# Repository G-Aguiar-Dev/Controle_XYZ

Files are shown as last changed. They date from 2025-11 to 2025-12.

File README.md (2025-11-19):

# 🏭 Controle XYZ - Sistema Automatizado de Armazém

**Sistema inteligente de armazenagem com CNC 3018, RFID e interface web**

[Início Rápido](#-início-rápido) • [Recursos](#-recursos) • [Hardware](#-hardware) • [Instalação](#-instalação) • [Documentação Completa](./DOCUMENTATION.md)

</div>

---

## 🎯 O que é?

**Controle XYZ** é um sistema automatizado de armazenagem executado em uma **Raspberry Pi Pico W**. Ele utiliza uma máquina CNC 3018 para movimentar pallets entre 6 posições de armazenamento, identificação por RFID, eletroímã para manipulação e uma interface web intuitiva para controle remoto.

O sistema funciona com **FreeRTOS** para multitarefa em tempo real e oferece um backend Flask com banco de dados SQLite para gestão de inventário e logs.

---

## ✨ Recursos Principais

- ✅ **Automação CNC 3D**: Movimento preciso em 3 eixos (X, Y, Z) com 6 posições de armazenamento
- ✅ **Identificação RFID**: Leitura automática de UIDs dos pallets (MFRC522)
- ✅ **Eletroímã Inteligente**: Pegar e soltar pallets automaticamente
- ✅ **Interface Web Responsiva**: Painel de controle moderno com real-time updates
- ✅ **Multitarefa em Tempo Real**: FreeRTOS com 2 tasks prioritárias
- ✅ **Display LCD**: Feedback visual no display 16x2 com I2C
- ✅ **Wi-Fi Integrado**: Servidor HTTP nativo no Pico W
- ✅ **Backend Python**: Gerenciamento de banco de dados SQLite
- ✅ **Sistema de Log Circular**: Histórico de operações em memória
- ✅ **Thread-Safe**: Proteção com mutexes para operações críticas

---

## 🔧 Hardware Necessário

| Componente | Especificação | Função |
|---|---|---|
| **Microcontrolador** | Raspberry Pi Pico W | Cérebro do sistema |
| **Motor XY** | NEMA 17 (2 unidades) | Movimentação horizontal |
| **Motor Z** | NEMA 17 | Movimentação vertical |
| **Drivers** | A4988 (3 unidades) | Controle dos motores |
| **Sensores** | Endstops (6 unidades) | Limites de movimento |
| **RFID** | MFRC522 | Identificação de pallets |
| **Eletroímã** | 24V DC | Pegar/soltar pallets |
| **Display** | LCD 16x2 I2C | Interface visual |
| **Máquina Base** | CNC 3018 | Estrutura mecânica |
| **Wi-Fi** | Integrado (Pico W) | Conectividade |

---

## 🚀 Início Rápido

### 1️⃣ Clonar o Repositório
```bash
git clone https://github.com/G-Aguiar-Dev/Controle_XYZ.git
cd Controle_XYZ
```

### 2️⃣ Compilar o Firmware
```bash
mkdir build && cd build
cmake ..
make -j4
```

### 3️⃣ Fazer Upload para Pico W
- Pressione **BOOTSEL** enquanto conecta o cabo USB
- Copie `Controle_XYZ.uf2` para a unidade PICO montada

### 4️⃣ Iniciar Backend Flask
```bash
python dbServer.py
```

### 5️⃣ Acessar a Interface
- Descobrir IP do Pico: Verifique saída serial
- Abrir navegador: `http://<IP_PICO>`

---

## 📁 Estrutura do Projeto

```
Controle_XYZ/
├── Controle_XYZ.c          # Firmware principal
├── CMakeLists.txt          # Build configuration
├── Index.html              # Interface web
├── dbServer.py             # Backend Flask
├── INSTALL.md              # Guia de instalação
├── README.md               # Este arquivo
├── DOCUMENTATION.md        # Documentação técnica completa
└── lib/
    ├── mfrc522.*           # Driver RFID
    ├── lcd_1602_i2c.*      # Driver LCD
    ├── HTML.*              # Gerador de HTML
    ├── FreeRTOSConfig.h    # Configuração FreeRTOS
    └── sqlite/             # SQLite
```

---

## 🎮 Como Usar

### Interface Web
1. **Armazenar Pallet**
   - Clique em "Iniciar Armazenamento"
   - Clique em uma célula vazia
   - Confirme a operação

2. **Retirar Pallet**
   - Clique em uma célula ocupada (amarela)
   - Confirme a remoção

3. **Controle Manual**
   - Botão de eletroímã para operações manuais
   - Visualize histórico de movimentações

### API HTTP
```bash
# Armazenar em A1
curl -X POST http://192.168.1.XX/store?slot=A1

# Retirar de B2
curl -X POST http://192.168.1.XX/retrieve?slot=B2

# Adicionar ao log
curl "http://192.168.1.XX/api/log?msg=Teste"
```

---

## 📊 Capacidade e Especificações

| Aspecto | Valor |
|---|---|
| **Posições de Armazenamento** | 6 (3 colunas × 2 linhas) |
| **Área de Trabalho** | 300mm × 180mm |
| **Velocidade XY** | ~800 µs por passo |
| **Velocidade Z** | ~1200 µs por passo |
| **Histórico de Logs** | 120 entradas (128 chars cada) |
| **Fila de Comandos** | 5 operações máximo |
| **Altura de Pickup** | 45mm |
| **Taxa de Atualização LCD** | ~1 Hz |

---

## 🔌 Configuração de Rede

```c
// Wi-Fi
SSID:  "Armazem XYZ"
PASS:  "tic37#grupo4"

// HTTP Server
PORT:  80 (Pico)
BACKEND: 5000 (Python)
```

---

## 📚 Documentação Completa

Para documentação técnica detalhada sobre funções, variáveis globais, tasks do FreeRTOS e troubleshooting, consulte:

➡️ **[DOCUMENTATION.md](./DOCUMENTATION.md)**

Inclui:
- Referência completa de funções
- Configuração de pinos GPIO
- Constantes de sistema
- Tasks do FreeRTOS
- Backend Flask API
- Exemplos de código

---

## 🐛 Troubleshooting Rápido

| Problema | Solução |
|---|---|
| **Wi-Fi não conecta** | Verifique SSID/senha e proximidade do roteador |
| **Motores não se movem** | Verifique alimentação dos drivers A4988 |
| **LCD em branco** | Confirme endereço I2C (0x27) e conexão |
| **RFID não lê cartão** | Verifique posicionamento e pinos SPI |
| **Homing não funciona** | Teste endstops com multímetro |

Mais detalhes em [DOCUMENTATION.md → Troubleshooting](./DOCUMENTATION.md#-troubleshooting)

---

## 📋 Requisitos de Compilação

- **Pico SDK** v1.5.0+
- **CMake** 3.13+
- **ARM GCC Toolchain**
- **FreeRTOS** com suporte RP2040
- **Python 3.8+** (para backend)

Veja [INSTALL.md](./INSTALL.md) para instruções completas de setup.

---

## 🔄 Fluxo de Operação

```
┌─────────────────────────────────────────────────┐
│  Sistema Inicia                                 │
│  1. Inicializa I2C/LCD                          │
│  2. Conecta Wi-Fi                               │
│  3. Inicializa RFID                             │
│  4. Cria Tasks FreeRTOS                         │
│  5. Executa Homing completo (0,0,0)             │
└─────────────────────────────────────────────────┘
                    ↓
┌─────────────────────────────────────────────────┐
│  Aguardando Comandos                            │
│  - Interface Web monitora estado                │
│  - Motor Task aguarda na fila                   │
│  - Polling Task mantém Wi-Fi ativo              │
└─────────────────────────────────────────────────┘
                    ↓
┌─────────────────────────────────────────────────┐
│  Comando Recebido (ex: /store?slot=A1)          │
│  1. Valida slot                                 │
│  2. Enfileira comando                           │
│  3. Motor Task processa:                        │
│     - Move para altura segura Z                 │
│     - Move para célula XY                       │
│     - Ativa eletroímã                           │
│     - Retorna altura segura                     │
│  4. Log registrado                              │
│  5. LCD atualizado                              │
└─────────────────────────────────────────────────┘
```

---

## 🤝 Contribuindo

Sugestões e melhorias são bem-vindas! Para contribuir:

1. Faça um Fork do projeto
2. Crie uma branch para sua feature (`git checkout -b feature/AmazingFeature`)
3. Commit suas mudanças (`git commit -m 'Add some AmazingFeature'`)
4. Push para a branch (`git push origin feature/AmazingFeature`)
5. Abra um Pull Request

---

## 📞 Contato e Suporte

- **Repositório**: [G-Aguiar-Dev/Controle_XYZ](https://github.com/G-Aguiar-Dev/Controle_XYZ)
- **Issues**: [GitHub Issues](https://github.com/G-Aguiar-Dev/Controle_XYZ/issues)

---

## 📜 Licença

Projeto desenvolvido para **EmbarcaTech 2025** pelo **Grupo 4 - Vitória da Conquista**.

</div>

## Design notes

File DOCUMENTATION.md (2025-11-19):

# 📚 Documentação Detalhada - Controle XYZ

Documentação completa das funções, variáveis globais e arquitetura do sistema automatizado de armazém.

## 📋 Índice

1. [Arquitetura do Sistema](#arquitetura-do-sistema)
2. [Configuração de Hardware](#configuração-de-hardware)
3. [Constantes de Funcionamento](#constantes-de-funcionamento)
4. [API de Funções](#api-de-funções)
5. [Tasks do FreeRTOS](#tasks-do-freertos)
6. [Variáveis Globais](#variáveis-globais)
7. [Backend Flask](#backend-flask)
8. [Interface Web](#interface-web)
9. [Exemplos de Uso](#exemplos-de-uso)
10. [Troubleshooting](#troubleshooting)

---

## 🏗️ Arquitetura do Sistema

### Hardware
- **Microcontrolador**: Raspberry Pi Pico W (RP2040 com Wi-Fi)
- **Motor de Movimento**: CNC 3018 com 3 eixos (X, Y, Z)
- **Sensores de Fim de Curso**: Endstops para cada eixo
- **Leitor RFID**: MFRC522 via SPI
- **Manipulador**: Eletroímã para pegar/soltar pallets
- **Display**: LCD 16x2 com I2C
- **Conectividade**: Wi-Fi integrada, Servidor HTTP

### Software
- **SO**: FreeRTOS em tempo real
- **Linguagem Principal**: C (Pico SDK)
- **Servidor Backend**: Python com Flask (dbServer.py)
- **Interface Web**: HTML5 + JavaScript

### Estrutura do Armazém
```
Área de Trabalho CNC 3018:
- Dimensão Total: 300mm (X) × 180mm (Y)
- Zona Útil: 250mm (X) × 130mm (Y)
- Distribuição: 3 colunas (A, B, C) × 2 linhas (1, 2)
- Margem: 25mm em cada lado

Posições das Células:
┌─────────────────────────────────┐
│  A1       B1       C1           │
│  (37.84,  (100.51, (163.18,     │
│   18.25)   18.25)   18.25)       │
│                                 │
│  A2       B2       C2           │
│  (37.84,  (100.51, (163.18,     │
│   53.75)   53.75)   53.75)       │
└─────────────────────────────────┘
```

---

## 🔧 Configuração de Hardware

### Configuração de Rede
- **SSID**: `Armazem XYZ`
- **Senha**: `tic37#grupo4`
- **Porta HTTP (Pico)**: 80
- **Porta Backend Flask**: 5000

### Configuração de Pinos

#### Eixo X (Motor Passo-Passo)
| Função | Pino |
|---|---|
| STEP | 14 |
| DIR | 15 |
| ENA | 16 |
| Endstop MIN | 10 |
| Endstop MAX | 13 |

#### Eixo Y (Motor Passo-Passo)
| Função | Pino |
|---|---|
| STEP | 1 |
| DIR | 2 |
| ENA | 0 |
| Endstop MIN | 11 |
| Endstop MAX | 17 |

#### Eixo Z (Motor Passo-Passo)
| Função | Pino |
|---|---|
| STEP | 21 |
| DIR | 22 |
| ENA | 20 |
| Endstop MIN | 12 |
| Endstop MAX | 18 |

#### Periféricos
| Periférico | Tipo | Pino/Barramento |
|---|---|---|
| Eletroímã | GPIO | 7 |
| RFID MFRC522 | SPI | (definido em mfrc522.h) |
| LCD 16x2 | I2C | SDA: 8, SCL: 9 |

---

## ⚙️ Constantes de Funcionamento

```c
// Velocidade de Movimento
STEP_DELAY_XY_US = 800  // Microssegundos entre pulsos (X e Y)
STEP_DELAY_Z_US = 1200  // Microssegundos entre pulsos (Z)

// Resolução de Movimento
STEPS_PER_MM_X = 50.0   // 50 passos por mm
STEPS_PER_MM_Y = 70.0   // 70 passos por mm
STEPS_PER_MM_Z = 50.0   // 50 passos por mm

// Altitudes do Eixo Z
Z_SAFE_MM = 0.0         // Altura segura (sem colisão)
Z_PICKUP_MM = 45.0      // Altura de pegar/soltar pallet
Z_TRAVEL_MAX_MM = 45.0  // Curso máximo

// I2C Configuration
I2C_PORT = i2c0
I2C_SDA = 8
I2C_SCL = 9
I2C_ADDR = 0x27         // Endereço do LCD

// Log circular
LOG_CAP = 120           // Máximo de linhas
LOG_LINE_MAX = 128      // Máximo de caracteres por linha

// RFID
UID_STRLEN = 32         // Tamanho da string UID
```

---

## 🚀 API de Funções

### Funções de Inicialização

#### `init_cnc_pins()`
**Propósito**: Inicializa todos os pinos GPIO dos motores e sensores  
**Retorno**: `void`  
**Detalhes**:
- Configura pinos de STEP, DIR e ENA como saída
- Configura pinos de endstops como entrada
- Inicializa pino do eletroímã

---

#### `start_http_server()`
**Propósito**: Inicia o servidor HTTP para comunicação com interface web  
**Retorno**: `void`  
**Detalhes**:
- Vincula a callback de conexão TCP
- Aguarda requisições HTTP na porta 80
- Processa rotas de API (GET, POST)

---

### Funções de Movimento

#### `step_motor(uint step_pin, uint dir_pin, bool direction, uint delay_us)`
**Propósito**: Gera um pulso de passo único para um motor  
**Parâmetros**:
- `step_pin`: GPIO do sinal de STEP
- `dir_pin`: GPIO do sinal de DIREÇÃO
- `direction`: true = frente, false = trás
- `delay_us`: Delay em microssegundos entre pulsos

**Detalhes**:
- Define direção no pino DIR
- Envia pulso HIGH-LOW no pino STEP
- Aguarda o tempo especificado

---

#### `home_all_axes()`
**Propósito**: Posiciona a máquina no ponto zero (0,0,0)  
**Retorno**: `void`  
**Detalhes**:
- Move cada eixo em direção ao endstop MIN
- Para quando endstop é acionado
- Atualiza posição global para (0, 0, 0)
- **Ordem**: Z primeiro, depois X, depois Y

---

#### `move_axes_to_steps(long target_x, long target_y, long target_z)`
**Propósito**: Move os eixos para posições específicas (em passos)  
**Parâmetros**:
- `target_x`: Posição-alvo X em passos
- `target_y`: Posição-alvo Y em passos
- `target_z`: Posição-alvo Z em passos

**Detalhes**:
- Calcula diferença entre posição atual e-alvo
- Move eixos independentemente até atingir alvo
- Verifica endstops durante movimento
- Atualiza `g_current_steps_*` globais

---

#### `execute_cell_operation(int cell_index, bool is_pickup_operation)`
**Propósito**: Executa operação completa de pegar ou guardar pallet  
**Parâmetros**:
- `cell_index`: Índice da célula (0-5)
- `is_pickup_operation`: true = pegar, false = guardar

**Detalhes**:
- Move para altura segura Z
- Move para posição X,Y da célula
- Lowera Z até altura de pickup
- Ativa/desativa eletroímã
- Retorna para altura segura
- Log de operação

---

### Funções de Conversão de Posição

#### `indice_para_slot(int idx)`
**Propósito**: Converte índice do array para nome do slot  
**Retorno**: String (ex: "A1", "B2", "C1")  
**Mapeamento**:
```
Índice → Slot
0      → A1
1      → A2
2      → B1
3      → B2
4      → C1
5      → C2
```

---

#### `slot_para_indice(char *slot)`
**Propósito**: Converte nome do slot para índice do array  
**Parâmetros**: `slot` - String (ex: "A1")  
**Retorno**: Índice (0-5) ou -1 se inválido  
**Exemplos**:
```c
"A1" → 0
"B2" → 3
"C1" → 4
"X5" → -1 (inválido)
```

---

### Funções do Eletroímã

#### `inicializa_eletroima()`
**Propósito**: Inicializa GPIO do eletroímã  
**Retorno**: `void`

---

#### `ativar_eletroima()`
**Propósito**: Ativa o eletroímã (coloca pino em HIGH)  
**Retorno**: `void`  
**Efeito**: Define `electromagnet_active = true`

---

#### `desativar_eletroima()`
**Propósito**: Desativa o eletroímã (coloca pino em LOW)  
**Retorno**: `void`  
**Efeito**: Define `electromagnet_active = false`

---

#### `toggle_eletroima()`
**Propósito**: Alterna estado do eletroímã (ativa ↔ desativa)  
**Retorno**: `void`

---

### Funções de Log

#### `log_push(const char *fmt, ...)`
**Propósito**: Adiciona mensagem formatada ao histórico circular  
**Parâmetros**: `fmt` - String com formato printf, seguido de argumentos  
**Detalhes**:
- Armazena até 120 linhas
- Máximo 128 caracteres por linha
- Buffer circular (sobrescreve entradas antigas)
- Thread-safe (usa mutex interno)

**Exemplos**:
```c
log_push("CNC: Iniciando Homing...");
log_push("Pallet %s moved to %s", uid, slot);
log_push("Erro: Slot inválido %d", cell_index);
```

---

#### `const char* log_get(int idx)`
**Propósito**: Recupera mensagem de log por índice  
**Parâmetros**: `idx` - Índice (0 = mais antigo)  
**Retorno**: Ponteiro para string do log  
**Detalhes**:
- Índices válidos: 0 a `g_log_count - 1`
- Retorna mensagens em ordem cronológica

---

### Funções RFID

#### `scan_for_uid(char* uid_buffer, size_t buffer_len)`
**Propósito**: Escaneia um cartão RFID e obtém sua UID  
**Parâmetros**:
- `uid_buffer`: Buffer para armazenar UID em string
- `buffer_len`: Tamanho máximo do buffer

**Retorno**: `true` se cartão lido com sucesso, `false` caso contrário  
**Detalhes**:
- Formato da UID: "12 34 56 78" (hex com espaços)
- Tenta por ~100ms
- Para o cartão automaticamente após leitura
- Thread-safe (com pausas para FreeRTOS)

**Exemplo**:
```c
char uid[32];
if (scan_for_uid(uid, sizeof(uid))) {
    printf("UID lida: %s\n", uid);
}
```

---

### Funções LCD

#### `lcd_update_line(int line, const char *fmt, ...)`
**Propósito**: Atualiza uma linha do display LCD (thread-safe)  
**Parâmetros**:
- `line`: Número da linha (0 ou 1)
- `fmt`: String com formato printf

**Detalhes**:
- Usa mutex para evitar conflito de acesso
- Trunca automaticamente para 16 caracteres
- Formata argumentos como `printf`

**Exemplos**:
```c
lcd_update_line(0, "Sistema Online");
lcd_update_line(1, "IP: 192.168.1.10");
lcd_update_line(0, "Celula %s", slot);
```

---

### Funções HTTP

#### `http_recv(void *arg, struct tcp_pcb *tpcb, struct pbuf *p, err_t err)`
**Propósito**: Callback para receber requisições HTTP  
**Retorno**: `ERR_OK` ou código de erro LWIP  
**Rotas Processadas**:

| Rota | Método | Descrição |
|---|---|---|
| `/api/log` | GET | Adiciona mensagem ao log |
| `/api/history` | GET | Retorna histórico em JSON |
| `/store` | POST | Guarda pallet em célula |
| `/retrieve` | POST | Retira pallet de célula |
| `/toggle-electromagnet` | POST | Alterna eletroímã |
| `/home` | POST | Retorna ao ponto zero |
| `/api/inventory` | GET | Retorna status das células |

**Formato de Query**:
```
/store?slot=A1      → Guarda em célula A1
/retrieve?slot=B2   → Retira de célula B2
/api/log?msg=Teste  → Log "Teste"
```

---

#### `query_param(const char *req, const char *key, char *out, size_t outsz)`
**Propósito**: Extrai parâmetro de query string  
**Parâmetros**:
- `req`: String com requisição HTTP completa
- `key`: Chave do parâmetro (ex: "slot")
- `out`: Buffer de saída
- `outsz`: Tamanho máximo

**Retorno**: `true` se parâmetro encontrado, `false` caso contrário  
**Detalhes**:
- Decodifica URL-encoded values automaticamente
- Busca após "?" na requisição

**Exemplo**:
```c
char slot[10];
if (query_param(req, "slot", slot, sizeof(slot))) {
    printf("Slot solicitado: %s\n", slot);
}
```

---

#### `url_decode_inplace(char *s)`
**Propósito**: Decodifica string URL-encoded (modifica in-place)  
**Parâmetros**: `s` - String para decodificar  
**Exemplos**:
```
"A%201" → "A 1"
"Test%20123" → "Test 123"
```

---

### Funções de Controle de Endstops

#### `check_endstop(uint pin)`
**Propósito**: Verifica se endstop está acionado  
**Parâmetros**: `pin` - GPIO do endstop  
**Retorno**: `true` se acionado, `false` caso contrário

---

#### Helpers para Endstops
- `check_endstop_x_min()` / `check_endstop_x_max()`
- `check_endstop_y_min()` / `check_endstop_y_max()`
- `check_endstop_z_min()` / `check_endstop_z_max()`

---

## 📋 Tasks do FreeRTOS

### `vPollingTask`
**Prioridade**: 1 (baixa)  
**Pilha**: 512 bytes  
**Função**:
- Executa `cyw43_arch_poll()` a cada 1 segundo
- Mantém conexão Wi-Fi ativa
- Loop infinito

---

### `vMotorControlTask`
**Prioridade**: 3 (alta)  
**Pilha**: 1024 bytes  
**Função**:
- Inicializa pinos da CNC
- Executa homing completo na inicialização
- Aguarda comandos na fila `g_movement_queue`
- Executa operações de movimento

**Fluxo**:
```
1. Inicializa pinos
2. Executa home_all_axes()
3. Move para posição segura Z
4. Loop:
   - Aguarda comando da fila (bloqueante)
   - Se comando de home: move para (0,0,0)
   - Senão: executa operação de célula
```

---

## 📊 Variáveis Globais

### Posição Atual
```c
volatile long g_current_steps_x;  // Posição X em passos
volatile long g_current_steps_y;  // Posição Y em passos
volatile long g_current_steps_z;  // Posição Z em passos
```

### Mapas de Posição
```c
CellPosition g_cell_map[6];       // Coordenadas das 6 células
char g_cell_uids[6][32];          // UIDs armazenadas em cada célula
```

### Sincronização
```c
SemaphoreHandle_t g_inventory_mutex;  // Protege g_cell_uids
SemaphoreHandle_t g_lcd_mutex;        // Protege LCD
QueueHandle_t g_movement_queue;       // Fila de comandos (5 itens)
```

### Estado
```c
bool electromagnet_active;        // true = ativo
MFRC522Ptr_t g_mfrc;             // Instância RFID
```

### Log
```c
char g_log[120][128];            // Buffer circular de logs
int g_log_head;                  // Índice da próxima escrita
int g_log_count;                 // Número de logs válidos
```

---

## 🌐 Backend Flask (dbServer.py)

O servidor Python gerencia o banco de dados SQLite com inventário e logs.

### Endpoints de Produtos
| Rota | Método | Descrição |
|---|---|---|
| `/api/products` | GET | Lista todos os produtos |
| `/api/products` | POST | Cria novo produto |
| `/api/products/<id>` | PUT | Atualiza produto |
| `/api/products/<id>` | DELETE | Deleta produto |

### Endpoints de Pallets
| Rota | Método | Descrição |
|---|---|---|
| `/api/pallet/register` | POST | Associa UID a produto |
| `/api/pallet/<uid>` | GET | Consulta pallet |
| `/api/pallet/<uid>` | PUT | Atualiza quantidade |
| `/api/pallet/<uid>` | DELETE | Deleta pallet |

### Endpoints de Logs
| Rota | Método | Descrição |
|---|---|---|
| `/api/log` | POST | Adiciona log |
| `/api/logs` | GET | Lista logs |
| `/api/status` | GET | Status do servidor |
| `/api/clear` | DELETE | Limpa todos os logs |

---

## 🎨 Interface Web

A interface web (`Index.html`) fornece:
- **Visualização do Layout**: Grid com 6 células (A1-C2)
- **Operações de Armazenagem**: Botão para ativar modo "guardar"
- **Operações Manuais**: Controle do eletroímã
- **Histórico**: Visualização de movimentações
- **Filtro**: Filtrar logs por data

### Funcionalidades JavaScript
- Requisições FETCH para endpoints HTTP/API
- Atualização dinâmica do visual das células
- Log local com timestamp
- Comunicação em tempo real com servidor

---

## 🔍 Exemplos de Uso

### Guardar Pallet na Célula A1
```javascript
fetch('/store?slot=A1', { method: 'POST' })
  .then(res => res.json())
  .then(data => console.log(data));
```

### Retirar Pallet da Célula B2
```javascript
fetch('/retrieve?slot=B2', { method: 'POST' })
  .then(res => res.json())
  .then(data => console.log(data));
```

### Adicionar Mensagem ao Log
```javascript
fetch('/api/log?msg=Teste%20manual', { method: 'GET' });
```

### Ativar Eletroímã
```javascript
fetch('/toggle-electromagnet', { method: 'POST' })
  .then(res => res.json());
```

---

## 🐛 Troubleshooting

### Problema: "Falha ao conectar Wi-Fi"
- Verifique SSID e senha em `Controle_XYZ.c`
- Confirme que o roteador está ativo
- Verifique distância/interferência

### Problema: "Endstop não acionado durante homing"
- Verifique conexão dos endstops
- Teste pinos com multímetro
- Revise pinos em `Controle_XYZ.c`

### Problema: "LCD não exibe mensagens"
- Verifique endereço I2C (padrão 0x27)
- Teste com exemplo de LCD I2C
- Confirme conexão SDA/SCL

### Problema: "RFID não detecta cartão"
- Verifique pinos SPI (MOSI, MISO, CLK, CS, RST)
- Tente ler versão: `PCD_DumpVersionToSerial()`
- Confirme cartão é compatível (ISO 14443A)

---

## 📝 Notas Importantes

1. **Thread Safety**: Sempre use `xSemaphoreTake()` ao acessar `g_cell_uids`
2. **Altitude Z Segura**: Sempre retorne a `Z_SAFE_MM` entre operações
3. **Homing Obrigatório**: Sistema sempre faz homing no startup
4. **Buffer de Log**: Máximo 120 linhas; entradas antigas são sobrescritas
5. **Velocidade de Movimento**: Ajuste `STEP_DELAY_*_US` para otimizar

---

## 📞 Referências Externas

- **Pico SDK**: https://github.com/raspberrypi/pico-sdk
- **FreeRTOS**: https://www.freertos.org/
- **LWIP**: https://savannah.nongnu.org/projects/lwip/
- **MFRC522**: http://www.nxp.com/documents/data_sheet/MFRC522.pdf
- **LCD 1602 I2C**: https://lastminuteengineers.com/lcd-i2c-address-scanner/

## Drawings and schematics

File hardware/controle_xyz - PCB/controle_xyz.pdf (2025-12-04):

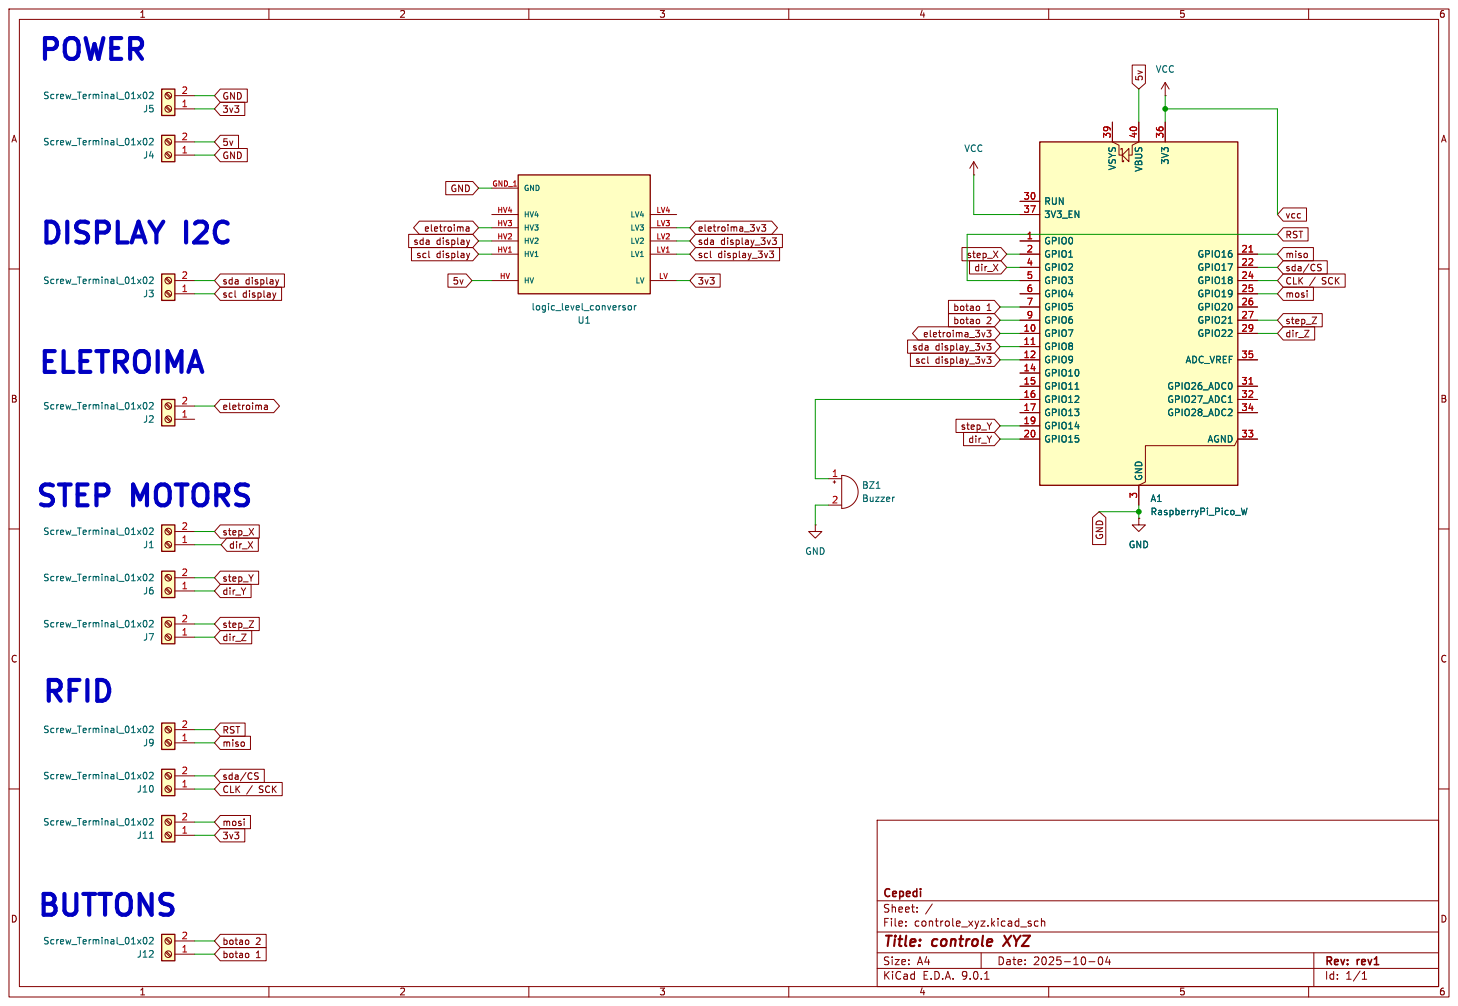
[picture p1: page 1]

miso RST CLK / SCK

Id: 1/1 Title: controle XYZ

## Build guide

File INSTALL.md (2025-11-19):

# Instruções para Executar o Servidor de Logs

## 1. Instalar Python

### Opção A: Via Microsoft Store (Recomendado)
1. Abra a Microsoft Store
2. Procure por "Python 3.11" ou "Python 3.12"
3. Clique em "Instalar"

### Opção B: Via python.org
1. Vá para https://www.python.org/downloads/
2. Baixe a versão mais recente para Windows
3. Execute o instalador
4. **IMPORTANTE**: Marque a opção "Add Python to PATH"

### Opção C: Via Terminal (Ubuntu/Linux)

1. sudo apt update
2. sudo apt install python3 python3-pip python3-venv

### Opção C: Via winget (se disponível)
```powershell
winget install Python.Python.3.11
```

## 2. Verificar Instalação

Após instalar, **feche e reabra o terminal**, então teste:

```powershell
python --version
```

Deve mostrar algo como: `Python 3.11.x`

## 3. Instalar Dependências

```powershell
pip install flask requests
```

## 4. Executar o Servidor

```powershell
python dbServer.py
ou
python3 dbServer.py
```

Você deve ver:
```
=== Controle XYZ - Servidor de Logs ===
Inicializando servidor...
Banco de dados inicializado: controle_xyz.db
Servidor rodando em: http://localhost:5000
Pressione Ctrl+C para parar o servidor
```

## 5. Testar o Servidor

Em outro terminal (deixe o servidor rodando):

```powershell
python test_server.py
```

## 6. Acessar via Navegador

- **Página inicial**: http://localhost:5000/
- **Ver Status e Estatísticas**: http://localhost:5000/api/status
- **Ver Lista de Produtos**: http://localhost:5000/api/products
- **Ver Lista de Logs**: http://localhost:5000/api/logs
- **Ver Pallet Específico**: http://localhost:5000/api/pallet/<uid>

## 7. Testar Manualmente (Testes POST, PUT, DELETE)

## Testar produtos

### POST (Exemplo):
```powershell / bash
curl -X POST http://localhost:5000/api/products \
     -H "Content-Type: application/json" \
     -d "{\"name\": \"Café\", \"default_quantity\": 25}"

```

### PUT (Exemplo):
```powershell / bash
curl -X PUT http://localhost:5000/api/products/4 \
     -H "Content-Type: application/json" \
     -d "{\"name\": \"Café Especial\", \"default_quantity\": 30}"

```

### DELETE (Exemplo):
```powershell / bash
curl -X DELETE http://localhost:5000/api/products/4

```

## Testar pallets

### POST (Exemplo):
```powershell / bash
curl -X POST http://localhost:5000/api/pallet/register \
     -H "Content-Type: application/json" \
     -d "{\"uid\": \"DD EE FF 00\", \"product_name\": \"Arroz\"}"

```

### PUT (Exemplo):
```powershell / bash
curl -X PUT "http://localhost:5000/api/pallet/<uid>" \
     -H "Content-Type: application/json" \
     -d "{\"current_quantity\": 10}"

```

### DELETE (Exemplo):
```powershell / bash
curl -X DELETE "http://localhost:5000/api/pallet/<uid>"

```

## Testando Logs

### POST (Exemplo):
```powershell / bash
curl -X POST http://localhost:5000/api/log \
     -H "Content-Type: application/json" \
     -d "{\"message\":\"Teste manual\", \"level\":\"INFO\"}"

```

### DELETE (Deletar todos os logs):
```powershell / bash
curl -X DELETE http://localhost:5000/api/clear

```

## 8. Integração com o Pico

1. Descubra o IP do seu computador:
   ```powershell
   ipconfig
   ```
   Procure por "Endereço IPv4" na seção da sua rede

2. No código do Pico (`Controle_XYZ.c`), altere:
   ```c
   #define DB_SERVER_IP "192.168.1.XXX"  // Substitua pelo IP do seu PC
   ```

3. Compile e execute o código do Pico

## Resolução de Problemas

### "Python não foi encontrado"
- Reinstale o Python marcando "Add to PATH"
- Reinicie o terminal/VS Code
- Tente `py` em vez de `python`

### "pip não foi encontrado"
```powershell
python -m ensurepip --upgrade
```

### "Servidor não conecta"
- Verifique se o firewall não está bloqueando a porta 5000
- Teste com `http://127.0.0.1:5000` em vez de `localhost`

### Porta já em uso
Altere a porta no `dbServer.py`:
```python
app.run(host='0.0.0.0', port=5001, debug=True)  # Mude para 5001
```

## Estrutura de Arquivos

Após executar, você terá:
```
projeto/
├── dbServer.py          # Servidor Flask
├── test_server.py       # Script de teste
├── controle_xyz.db      # Banco SQLite (criado automaticamente)
├── INSTALL.md           # Este arquivo
└── Controle_XYZ.c       # Código do Pico
```

## Endpoints da API

### Produtos

- `GET /api/products` — Listar todos os produtos
- `POST /api/products` — Criar novo produto
- `PUT /api/products/<id>` — Atualizar produto
- `DELETE /api/products/<id>` — Deletar produto

### Pallets

- `POST /api/pallet/register` — Associar/resetar UID
- `GET /api/pallet/<uid>` — Consultar pallet específico
- `PUT /api/pallet/<uid>` — Atualizar quantidade
- `DELETE /api/pallet/<uid>` — Deletar pallet

### Logs e status

- `GET /` — Página inicial
- `GET /api/status` — Status e estatísticas
- `POST /api/log` — Adicionar log
- `GET /api/logs` — Listar logs
- `DELETE /api/clear` — Limpar todos os logs

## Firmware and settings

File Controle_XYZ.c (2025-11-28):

// Bibliotecas
#include "pico/stdlib.h"        // Biblioteca padrao do Pico
#include "pico/multicore.h"     // Biblioteca para suporte a múltiplos núcleos na Raspberry Pi Pico
#include "hardware/gpio.h"      // Biblioteca de GPIO
#include "hardware/adc.h"       // Biblioteca de ADC
#include "hardware/i2c.h"       // Biblioteca de I2C
#include "hardware/clocks.h"    // Biblioteca de clocks
#include "hardware/spi.h"       // Biblioteca de SPI

#include "pico/cyw43_arch.h"    // Biblioteca para arquitetura Wi-Fi da Pico com CYW43
#include "lwip/tcp.h"           // Biblioteca de LWIP para manipulacao de TCP/IP

#include "FreeRTOS.h"           // Biblioteca de FreeRTOS
#include "task.h"               // Biblioteca de tasks
#include "queue.h"              // Biblioteca de listas
#include "semphr.h"             // Biblioteca para Mutex/Semaforos

#include "lib/HTML.h"           // Biblioteca para geracao de HTML
#include "lib/lcd_1602_i2c.h"   // Biblioteca para Display LCD
#include "lib/mfrc522.h"        // Biblioteca para o Sensor RFID

#include <stdio.h>              // Biblioteca de entrada e saida padrao
#include <stdlib.h>             // Biblioteca padrao
#include <string.h>             // Biblioteca de strings
#include <ctype.h>              // Biblioteca de caracteres
#include <stdarg.h>             // Biblioteca para manipulacao de argumentos variaveis
#include <math.h>               // Biblioteca matematica

//----------------------------------VaRIAVEIS GLOBAIS----------------------------------

#define WIFI_SSID ""                    // Nome da rede Wi-Fi
#define WIFI_PASS ""                   // Senha da rede Wi-Fi

// Configuracoes do eletroima
#define ELECTROMAGNET_PIN 7    // Pino do eletroima

// Pinos Eixo X
#define STEP_PIN_X 14
#define DIR_PIN_X 15
#define ENA_PIN_X 16
#define ENDSTOP_PIN_X 10 

// Pinos Eixo Y
#define STEP_PIN_Y 1
#define DIR_PIN_Y 2
#define ENA_PIN_Y 0
#define ENDSTOP_PIN_Y 11 

// Pinos Eixo Z
#define STEP_PIN_Z 21
#define DIR_PIN_Z 22
#define ENA_PIN_Z 20
#define ENDSTOP_PIN_Z 12 


// Ex: (200 * 8 micro) / 8mm avanco = 200.0
#define STEPS_PER_MM_X 50.0
#define STEPS_PER_MM_Y 70.0
// Ex: (200 * 8 micro) / 4mm avanco = 400.0
#define STEPS_PER_MM_Z 50.0 

typedef struct {
    float x_mm;       // Distancia X (em mm) do centro da celula
    float y_mm;       // Distancia Y (em mm) do centro da celula
} CellPosition;

// --- DEFINICOES DA CNC 3018 ---
// Area de trabalho total: 300mm (X) por 180mm (Y)
//
// Area util X: 300mm - (2 * 25mm) = 250mm
// Area util Y: 180mm - (2 * 25mm) = 130mm
//
// Tamanho da Celula X: 250mm / 3 colunas = 83.33mm
// Tamanho da Celula Y: 130mm / 2 linhas = 65.0mm
//
// Offset (Margem): X=25mm, Y=25mm
//
// Coordenadas dos Centros das Celulas:
// X_Col_A = 25.0 (Offset) + (83.33 / 2) = 71.67mm
// X_Col_B = 25.0 (Offset) + 83.33 + (83.33 / 2) = 150.0mm
// X_Col_C = 25.0 (Offset) + (2 * 83.33) + (83.33 / 2) = 233.33mm
//
// Y_Linha_1 = 25.0 (Offset) + (65.0 / 2) = 57.5mm
// Y_Linha_2 = 25.0 (Offset) + 65.0 + (65.0 / 2) = 122.5mm
//

CellPosition g_cell_map[6] = {
    { .x_mm = 37.84, .y_mm = 18.25 },    // Celula 0 ("A1")
    { .x_mm = 37.84, .y_mm = 53.75 },    // Celula 1 ("A2")
    { .x_mm = 100.51, .y_mm = 18.25 },   // Celula 2 ("B1")
    { .x_mm = 100.51, .y_mm = 53.75 },   // Celula 3 ("B2")
    { .x_mm = 163.18, .y_mm = 18.25 },   // Celula 4 ("C1")
    { .x_mm = 163.18, .y_mm = 53.75 }    // Celula 5 ("C2")
};

#define Z_TRAVEL_MAX_MM 45.0    // Curso maximo fisico do Eixo Z
#define Z_SAFE_MM 0.0           // Altura Z segura 
#define Z_PICKUP_MM 45.0        // Altura Z para pegar/soltar (45mm abaixo do topo)

// Delay (em microssegundos) entre pulsos do motor. Controla a velocidade.
#define STEP_DELAY_XY_US 800  // Delay para os eixos X e Y
#define STEP_DELAY_Z_US 1200  // Delay mais lento para o Eixo Z

// Posicao atual da maquina, em PASSOS.
volatile long g_current_steps_x = 0;
volatile long g_current_steps_y = 0;
volatile long g_current_steps_z = 0;

// Guarda a ultima posicao alvo (em passos) enviada para X/Y.
volatile long g_last_target_steps_x = 0;
volatile long g_last_target_steps_y = 0;

// I2C para o display
#define I2C_PORT i2c0
#define I2C_SDA 8
#define I2C_SCL 9
#define I2C_ADDR 0x27 

QueueHandle_t g_movement_queue; // Fila de comandos de movimento

// Estrutura do comando de movimento
typedef struct {
    int cell_index;             // indice da celula (0-5)
    bool is_store_operation;    // true = guardar (soltar), false = retirar (pegar)
} MovementCommand;

// Struct para manter o estado da conexao HTTP
struct http_state                               
{
    const char *response_ptr;   // ponteiro para o buffer com a resposta
    char smallbuf[1024];        // usado para respostas pequenas/JSON
    size_t len;                 // tamanho total da resposta
    size_t sent;
    size_t offset;              // bytes ja enfileirados para envio
    bool using_smallbuf;
};

// Historico de logs em memoria
#define LOG_CAP 120
#define LOG_LINE_MAX 128
static char g_log[LOG_CAP][LOG_LINE_MAX];
static int g_log_head = 0;  // aponta para a proxima posicao de escrita
static int g_log_count = 0; // quantos registros validos

// Variavel do eletroima
bool electromagnet_active = false;

MFRC522Ptr_t g_mfrc; // Ponteiro global para a instancia do MFRC522

#define UID_STRLEN 32                           // Espaco para UID (ex: "12 34 56 78 ")
static char g_cell_uids[6][UID_STRLEN];         // Armazena a UID de qual pallet esta em qual slot
static SemaphoreHandle_t g_inventory_mutex;     // Protege g_cell_uids
static SemaphoreHandle_t g_lcd_mutex;           // Protege g_cell_uids

// Estrutura para armazenar tokens válidos em memória
#define MAX_ACTIVE_TOKENS 10
typedef struct {
    char token[512];
    uint32_t timestamp;
    bool active;
} Token;

static Token active_tokens[MAX_ACTIVE_TOKENS];
static int token_count = 0;

//---------------------------------------FUNcoES---------------------------------------

void core1_polling(void);

// Funcoes do servidor HTTP
static void send_next_chunk(struct tcp_pcb *tpcb, struct http_state *hs);
static err_t http_sent(void *arg, struct tcp_pcb *tpcb, u16_t len);
static err_t http_recv(void *arg, struct tcp_pcb *tpcb, struct pbuf *p, err_t err);
static err_t connection_callback(void *arg, struct tcp_pcb *newpcb, err_t err);
static void start_http_server(void);
static int url_hex(char c);
static void url_decode_inplace(char *s);
static bool query_param(const char *req, const char *key, char *out, size_t outsz);

// Funcoes para movimentacao dos eixos
static void init_cnc_pins(void);
static void step_motor(uint step_pin, uint dir_pin, bool direction, uint delay_us);
static void home_all_axes(void);
static void move_axes_to_steps(long target_x, long target_y, long target_z);
static void execute_cell_operation(int cell_index, bool is_pickup_operation);
static int slot_para_indice(char *slot); 
static const char* indice_para_slot(int idx);

// Funcoes do eletroima
static void inicializa_eletroima(void);
static void ativar_eletroima(void);
static void desativar_eletroima(void);
static void toggle_eletroima(void);

// Funcoes de log
static void log_push(const char *fmt, ...);
static const char *log_get(int idx);
static bool scan_for_uid(char* uid_buffer, size_t buffer_len);

// Funcoes do display LCD I2C
void lcd_update_line(int line, const char *fmt, ...);

// Função para validar token
static bool validate_token(const char *token);

// Extrair token do header Authorization
static bool extract_token(const char *req, char *token_out, size_t out_len);

//----------------------------------------TASKS----------------------------------------

void core1_polling() 
{
    printf("\n=== Inicializando Stack de Rede... ===\n", get_core_num());

    // 1. Inicializa hardware Wi-Fi (NO CORE 1)
    if (cyw43_arch_init()) {
        printf("ERRO FATAL: Falha Wi-Fi init\n", get_core_num());
        return;
    }

    cyw43_arch_enable_sta_mode();
    
    // Atualiza LCD (usando Mutex pois I2C é compartilhado)
    lcd_update_line(1, "Conectando...");
    printf("Conectando ao Wi-Fi...\n", get_core_num());

    // 2. Conecta ao Wi-Fi (NO CORE 1)
    if (cyw43_arch_wifi_connect_timeout_ms(WIFI_SSID, WIFI_PASS, CYW43_AUTH_WPA2_AES_PSK, 15000)) {
        printf("ERRO: Falha conexao Wi-Fi\n", get_core_num());
        lcd_update_line(1, "WIFI CONNECT FALHOU");
    } else {
        // Sucesso na conexão
        uint8_t *ip = (uint8_t *)&(cyw43_state.netif[0].ip_addr.addr);
        printf("CONECTADO! IP: %d.%d.%d.%d\n", get_core_num(), ip[0], ip[1], ip[2], ip[3]);
        
        char ip_buffer[17];
        snprintf(ip_buffer, 17, "IP:%d.%d.%d.%d", ip[0], ip[1], ip[2], ip[3]);
        lcd_update_line(1, ip_buffer);
        
        // 3. Inicia Servidor HTTP (NO CORE 1)
        start_http_server();
    }

    // 4. Loop infinito de processamento de rede
    while (true)
    {
        // Como o init foi feito neste core, os callbacks virão para cá.
        cyw43_arch_poll(); 
        
        sleep_ms(1); 
    }
}

// Task de controle da CNC
void vMotorControlTask(void *pvParameters)
{
    printf("Motor Task iniciada. Inicializando pinos da CNC...\n");
    init_cnc_pins();

    // 1. Zera a maquina ANTES de aceitar qualquer comando
    printf("Iniciando Homing da CNC...\n");
    log_push("CNC: Iniciando Homing...");
    lcd_update_line(0, "Iniciando Homing");  
    lcd_update_line(1, "Aguarde...");        
    
    //home_all_axes();
    
    printf("Homing concluido! Maquina em (0, 0, 0).\n");
    log_push("CNC: Homing concluido.");
    lcd_update_line(0, "Status: Pronto");  
    lcd_update_line(1, "");             

    // Converte Z_SAFE_MM para passos
    long z_safe_steps = (long)(Z_SAFE_MM * STEPS_PER_MM_Z);
    
    // 2. Move para uma posicao inicial segura
    move_axes_to_steps(g_current_steps_x, g_current_steps_y, z_safe_steps);

    MovementCommand cmd;

    // 3. Loop principal: Aguarda comandos da Fila
    while (true)
    {
        // Aguarda um comando da fila (vindo do http_recv)
        if (xQueueReceive(g_movement_queue, &cmd, portMAX_DELAY) == pdPASS)
        {
            // Verifica se e um comando de home (cell_index == -1)
            if (cmd.cell_index == -1) {
                printf("Comando de HOME recebido. Retornando a (0,0,0)...\n");
                log_push("CNC: Retornando ao home (0,0,0)");
                lcd_update_line(0, "Retornando Home");
                lcd_update_line(1, "Aguarde...");
                
                // Move para (0,0,0)
                move_axes_to_steps(0, 0, 0);
                
                log_push("CNC: Home concluido (0,0,0)");
                printf("Retorno ao home concluido.\n");
                lcd_update_line(0, "Status: Pronto");
                lcd_update_line(1, "Home OK");
            } else {
                // Comando normal de celula
                printf("Comando recebido: Celula %d, Operacao: %s\n", 
                       cmd.cell_index, cmd.is_store_operation ? "GUARDAR" : "RETIRAR");
                
                bool is_pickup = !cmd.is_store_operation;
                
                // 4. Chama a funcao de movimento
                execute_cell_operation(cmd.cell_index, is_pickup);
            }
        }
    }
}

//----------------------------------------MAIN-----------------------------------------

int main()
{
    stdio_init_all();
    sleep_ms(4000); // Delay para o monitor serial conectar

    // --- INICIALIZA I2C E LCD ---
    i2c_init(I2C_PORT, 100 * 1000); 
    gpio_set_function(I2C_SDA, GPIO_FUNC_I2C);
    gpio_set_function(I2C_SCL, GPIO_FUNC_I2C);
    gpio_pull_up(I2C_SDA);
    gpio_pull_up(I2C_SCL);
    sleep_ms(100); 

    lcd_init(I2C_PORT, I2C_ADDR);
    lcd_clear();
    lcd_set_cursor(0, 0);
    lcd_string("Iniciando...");
    lcd_set_cursor(1, 0);
    lcd_string("v1.0");

    // --- CRIA O MUTEX DO LCD ---
    g_lcd_mutex = xSemaphoreCreateMutex();
    if (g_lcd_mutex == NULL) {
        printf("Falha ao criar Mutex do LCD!\n");
        lcd_set_cursor(0, 0); lcd_string("ERRO FATAL");
        lcd_set_cursor(1, 0); lcd_string("MUTEX LCD FALHOU");
        while(true); // Trava aqui
    }

    // --- CRIA O MUTEX DO INVENTARIO ---
    g_inventory_mutex = xSemaphoreCreateMutex();
    if (g_inventory_mutex == NULL) {
        printf("Falha ao criar Mutex de Inventario!\n");
        lcd_update_line(0, "ERRO FATAL");
        lcd_update_line(1, "MUTEX INV. FALHOU");
        while(true);
    }
    // Inicializa o inventario como vazio
    for (int i = 0; i < 6; i++) {
        g_cell_uids[i][0] = '\0';
    }

    multicore_launch_core1(core1_polling);

    // --- INICIALIZA RFID ---
    // (Assume que os pinos SPI, CS, RST estao definidos em lib/mfrc522.h)
    printf("Inicializando leitor RFID MFRC522...\n");
    lcd_update_line(1, "Iniciando RFID...");
    
    g_mfrc = MFRC522_Init();
    PCD_Init(g_mfrc, spi0); // Usa spi0 como no seu exemplo
    
    printf("RFID MFRC522: ");
    PCD_DumpVersionToSerial(g_mfrc); // Imprime a versao do firmware no console
    
    lcd_update_line(1, "RFID OK.");
    sleep_ms(500);


    inicializa_eletroima();
    multicore_launch_core1(core1_polling);
    start_http_server();

    // Cria a fila para 5 comandos de movimento
    g_movement_queue = xQueueCreate(5, sizeof(MovementCommand)); 
    if (g_movement_queue == NULL) {
         printf("Falha ao criar a Fila de Movimento!\n");
         lcd_update_line(0, "ERRO FATAL");
         lcd_update_line(1, "FILA MOV. FALHOU");
         while(true);
    }

    // --- Tasks do FreeRTOS ---
    xTaskCreate(vMotorControlTask, "Motor Task", 1024, NULL, 3, NULL); // Prioridade alta

    printf("Iniciando Scheduler do FreeRTOS...\n");
    vTaskStartScheduler();
    
    panic_unsupported();
}

//---------------------------------DECLARAcaO DAS FUNcoES-----------------------------

// -------------------- Funcoes Servidor HTTP --------------------

#define CHUNK_SIZE 1024

// Funcao para enviar o proximo pedaco de resposta se houver espaco na janela
static void send_next_chunk(struct tcp_pcb *tpcb, struct http_state *hs)
{
    if (hs->offset >= hs->len)
        return;
    size_t remaining = hs->len - hs->offset;
    size_t to_send = remaining > CHUNK_SIZE ? CHUNK_SIZE : remaining;
    if (tcp_sndbuf(tpcb) < to_send)
        return; // Aguardar janela
    err_t err = tcp_write(tpcb, hs->response_ptr + hs->offset, to_send, TCP_WRITE_FLAG_COPY);
    if (err == ERR_OK)
    {
        hs->offset += to_send;
        tcp_output(tpcb);
    }
    else if (err != ERR_MEM)
    {
        // log erro irreversivel
        printf("tcp_write fatal: %d\n", err);
    }
}

// Funcao de callback para enviar dados HTTP
static err_t http_sent(void *arg, struct tcp_pcb *tpcb, u16_t len)
{
    struct http_state *hs = (struct http_state *)arg;
    hs->sent += len;
    if (hs->sent >= hs->len)
    {
        tcp_close(tpcb);
        free(hs);
    }
    else
    {
        send_next_chunk(tpcb, hs);
    }
    return ERR_OK;
}

// Funcao para escanear por um cartao RFID e obter sua UID
static bool scan_for_uid(char* uid_buffer, size_t buffer_len) {
    if (g_mfrc == NULL) return false;
    
    memset(uid_buffer, 0, buffer_len);

    // Tenta por ~100ms
    for (int i = 0; i < 2; i++) {
        // Procura por novos cartoes
        if (PICC_IsNewCardPresent(g_mfrc)) {
            // Seleciona um dos cartoes
            if (PICC_ReadCardSerial(g_mfrc)) {
                // Formata a UID em string
                int offset = 0;
                for (int j = 0; j < g_mfrc->uid.size && offset < (buffer_len - 4); j++) {
                    // Adiciona um espaco entre os bytes
                    offset += snprintf(uid_buffer + offset, buffer_len - offset, "%02X ", g_mfrc->uid.uidByte[j]);
                }
                uid_buffer[offset > 0 ? offset - 1 : 0] = '\0'; // Remove o ultimo espaco

                PICC_HaltA(g_mfrc); // Para o cartao
                return true; // Sucesso
            }
        }
        vTaskDelay(pdMS_TO_TICKS(50)); // Pequena espera
    }

    return false; // Nao encontrou
}
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

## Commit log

2025-08-26 feat: adição de funções para server side http
2025-08-29 build: arquivos de configuração de IP && fix: CMakeLists.txt
2025-08-29 fix: ajuste de nome das posições dos pallets
2025-08-29 feat: adição das variáveis para JSON && feat: Endpoint JSON
2025-09-08 feat: implementa controle de matriz LED e atualiza HTML para painel de controle
    - Adiciona funções para controle de matriz LED, incluindo acender e apagar LEDs com base em parâmetros de URL.
    - Atualiza o arquivo HTML com layout e estilo para o painel de controle do armazém.
    - Modifica CMakeLists.txt para incluir novos arquivos e bibliotecas necessárias.
    - Aumenta o buffer de resposta HTML para suportar conteúdo maior.
2025-09-08 feat: adiciona controle do eletroímã e atualiza HTML para integração
    - Implementa funções para inicializar, ativar, desativar e alternar o estado do eletroímã.
    - Adiciona endpoint JSON para obter o status do eletroímã.
    - Atualiza o HTML para incluir botões e lógica de controle do eletroímã, permitindo interação do usuário.
    - Melhora a estrutura do código para gerenciar o estado do eletroímã de forma eficiente.
2025-09-09 Adição do histórico. Modificação dos exemplos que estavam no site HTML, como de ID e células ocupadas.
2025-09-10 Funcionalidades de responsividade funcionando novamente. Junto com o histórico.
2025-09-12 feat: hooks de malloc e overflow e verificação de conexões http && ajuste do buffer html && heapsize + parâmetros de verificação do RTOS
2025-09-19 Adição de funcionalidades na página HTML.
2025-09-20 Ao tentar remover de uma posição que não possui nenhum pallet, ele mostra uma aviso de erro.
2025-09-25 Retirada de algumas funcionalidades da página web. Bem como a adição da opção de acrescentar um pallet em uma célula ao iniciar o armazenamento.
2025-09-29 Adição de funcionalidades para controle manual com botões, incluindo inicialização, processamento de entradas e atualização do display. Implementação de uma nova task para gerenciar o controle dos bo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
2025-10-02 Correção dos problemas de 'Out of memory'. Resposta ao usuário também funcionando novamente.
    [Controle_XYZ.c]
2025-10-04 add HW schematic
    [controle_xyz.kicad_pcb, controle_xyz.kicad_sch]
2025-10-08 feat: Banco de Dados para Logs
2025-10-10 Servidor com banco de dados funcionando para interações com os botões da página web.
2025-10-13 update hw sch
    [Esquematico_Eletrico_01.kicad_sch, controle_xyz.kicad_sch]
2025-10-23 Enhance hardware schematic: Added new junctions, wires, and global labels for improved connectivity and clarity in the controle_xyz schematic.
    [controle_xyz.kicad_sch]
2025-10-27 update esquematico
    [controle_xyz.kicad_sch]
2025-10-27 feat: funções para controle de hardware do protótipo && cleanup: limpeza de código da matriz de LEDs
    [Esquematico_Eletrico_01.kicad_sch, controle_xyz.kicad_pcb, controle_xyz.kicad_sch]
2025-11-10 Alteração para integração de RFID com o banco de dados.
2025-11-13 Atualização do banco de dados e da interface web.
2025-11-16 teste de push
2025-11-16 refactor: reorganiza pinos de fim de curso e implementa verificação de limites
    - Renomeia e redefine os pinos de fim de curso para os eixos X, Y e Z, melhorando a clareza do código.
    - Implementa funções para verificar os limites dos eixos durante o movimento, garantindo maior segurança e controle.
    - Atualiza a rotina de homing para utilizar os novos pinos e lógica de verificação, otimizando o processo de inicialização da máquina.
2025-11-21 Retirando as linhas de logs da página HTML.
2025-11-21 Utilização do core1 no código principal para realizar polling do wifi.
2025-11-26 Utitilizando o Core 1 para as funções de Wifi e HTTP.
2025-11-27 feat: adição das tabelas de usuários
2025-11-27 feat: endpoints de autenticação
2025-11-27 feat: validação de tokens
2025-11-27 feat: Página de Login adicionada ao HTML
2025-11-27 add: avisos de modificação de senhas padrão
2025-12-04 adiciona novo hardware para pcb
    [Esquematico_Eletrico_01.kicad_sch, controle_xyz.kicad_pcb, controle_xyz.kicad_sch]
2025-12-05 Conectores de Borne Atualizados
    [controle_xyz.kicad_pcb, controle_xyz.kicad_sch]
